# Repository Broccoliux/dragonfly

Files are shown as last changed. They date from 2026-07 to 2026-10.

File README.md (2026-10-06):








 
---
 
# Dragonfly
 
A custom all-in-one flight controller + ESC, built entirely from discrete ICs rather than premade modules, designed for me by me. Flight control and all 4 motor drivers live on a single 4-layer PCB, designed from scratch in KiCad.
 
# Why I Built This
 
I wanted to go past just building a flight controller most DIY FC projects stop at a board that reads a gyro and outputs signals. I wanted the whole thing: FC and ESC combined on one board, IC-level design instead of stacking pre-built modules, a custom 3D-printed frame, and firmware configured to actually fly and hold up to real maneuvers, not just hover.
 
This became a fromscratch systems project schematic, PCB layout, mechanical frame design, and firmware, all built and understood end-to-end rather than assembled from a kit.
 
---
     
## Features
 
- 4-layer PCB designed from scratch in KiCad, all-in-one FC + ESC on a single board
- STM32F405RGTx flight controller MCU running Betaflight, custom unified target
- 4x independent ESC channels, each with its own AT32F421G8U7 MCU running AM32 firmware real per-motor commutation, not a single shared driver
- FD6288Q 3-phase gate drivers + discrete MOSFETs per channel, sized for freestyle current draw, not just hover
- ICM-20602 IMU (SPI), isolated placement and routing to minimize motor-noise coupling into gyro data
- AT7456E OSD for FPV video overlay (battery voltage, timer)
- BMP280 barometer for altitude hold
- TPS5430 buck (5V) + AMS1117-3.3 LDO + dedicated L78L08 8V rail for gate drivers — separate, correctly isolated power domains
- Individual SWD test points per ESC channel for one-time AM32 flashing
- ELRS receiver support (Happymodel Nano RX) over UART
- Custom 3" toothpick-class frame, designed in Fusion 360, 3D printed
- **Estimated build cost:** ~$250–300 (board, motors, frame, battery, receiver, transmitter)
---
 
## What's Inside
 
| Component | Part | Specification |
|---|---|---|
| Flight Controller MCU | STM32F405RGTx | ARM Cortex-M4, 168 MHz |
| IMU | ICM-20602 | 6-axis, SPI |
| ESC MCU (x4) | AT32F421G8U7 | One per motor, runs AM32 |
| Gate Driver (x4) | FD6288Q | 3-phase, one per motor |
| Motor Drive | 6x MOSFET per channel | 24 total, sized for real current draw |
| Buck Regulator | TPS5430 | Battery → 5V |
| LDO | AMS1117-3.3 | 5V → 3.3V |
| Gate Driver Supply | L78L08 | Battery → 8V, dedicated rail |
| OSD | AT7456E | Analog FPV video overlay |
| Barometer | BMP280 | Altitude hold |
| Receiver | Happymodel ELRS Nano RX | UART |
| Transmitter | RadioMaster Zorro (ELRS) | Full-size hall gimbals |
| Motors | 3" class, 1404, ~3800–4500KV | 4S |
| Frame | Custom 3" toothpick | 3D printed, Fusion 360 |
| PCB | 4-layer | KiCad |
 
---
 
## Firmware
 
**Status:** in progress configuration and pin-mapping stage, not reqady to flash
 
Two separate firmware bases run on this board:
 
- **Betaflight** (main STM32F405) custom unified target describing this board's exact pin map (motors, IMU SPI, receiver UART)
- **AM32** (each of the 4 AT32F421 ESC MCUs) open-source ESC firmware, flashed individually per channel via dedicated SWD test points
```bash
firmware/
├── betaflight-unified-target/   # Unified target config for the main FC
├── am32/                        # AM32 firmware source, per-channel builds
└── notes.md                     # Pin mapping reference
```
 
---
 
## How to Use
 
### Hardware
 
1. PCB files are located in `PCB/`
2. Open the `.kicad_pro` file in KiCad 8+
3. Upload Gerbers from `PCB/gerbers/` to JLCPCB (4-layer)
4. Order components using `BOM/BOM.csv`
5. Frame STEP file is available in `CAD/`
### Firmware
 
1. Flash AM32 onto each of the 4 ESC MCUs individually, using the SWD test points per channel
2. Flash Betaflight onto the main STM32 via USB-C, using the custom unified target in `firmware/betaflight-unified-target/`
3. Configure IMU calibration, receiver binding, and OSD via Betaflight Configurator
---
 
## Repository Structure
 
```text
Dragonfly/
├── PCB/                         # KiCad project + Gerbers
├── CAD/                         # Fusion 360 frame design (.step)
├── firmware/                    # Betaflight unified target + AM32
├── BOM/                         # Bill of Materials
├── imgs/                        # Photos and renders
└── README.md
```
 
---
 
## Built By
 
**broccoli 🥦** — Solo hardware builder from Pakistan.
 
*Chasing what I love. GE0*

'geo geo geo

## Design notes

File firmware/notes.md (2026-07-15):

| Function | MCU Pin | Notes |
| --- | --- | --- |
| Motor 1 signal | PA8 | TIM1 CH1, DShot |
| Motor 2 signal | PA9 | TIM1 CH2, DShot (check UART1 conflict) |
| Motor 3 signal | PA10 | TIM1 CH3, DShot (check UART1 conflict) |
| Motor 4 signal | PA11 | TIM1 CH4, DShot |
| IMU SPI | TBD | ICM-20602, SPI, CS/SCK/MISO/MOSI |
| Receiver UART | TBD | ELRS, avoid USART1 if motors use PA9/PA10 |

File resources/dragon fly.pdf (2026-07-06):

## BROCCOLI BOARD LAB

# Phased Build Guide

## Custom FC+ESC Drone — Component by Component, Item by Item

Revised: freestyle-capable ESC · custom 3D-printed frame · transmitter included

Prepared for broccoli ■ — July 2026

Phased Build Guide — Custom FC+ESC Drone | Page 2

# Index

Index | 2
How This Guide Works | 3
Designing the Custom 3D-Printed Frame | 9
Appendix — Updated Bill of Materials | 10

# How This Guide Works

Each component is one phase. Each phase has numbered items — the exact supporting parts (capacitors, resistors, ferrite beads, crystals) that go with that component. Finish every item in a phase, double-check it against the datasheet reference, then move to the next phase. Don't jump ahead — if something breaks later, you want to know it's isolated to the most recent phase, not spread across five half-finished ones.
Build order: MCU → IMU → ESC channel (repeated 4x, one per motor) → Power → Peripherals. This order is deliberate — the MCU's pin assignments have to be locked before anything else can be wired to them.

Phase 1: Microcontroller — STM32F405RGT6

## PHASE 1: Microcontroller — STM32F405RGT6

LQFP-64 · the flight computer · lock every pin assignment here before moving on

Item 1: Power pins
- 100nF ceramic decoupling capacitor on every single VDD pin — do not skip any.
- 1x 4.7–10µF bulk capacitor on the main VDD rail.

Item 2: Analog reference
- 100nF + 1µF on VDDA/VREF+, isolated from digital VDD with a small ferrite bead.

Item 3: Backup rail
- 10nF + 1µF on VBAT, even without a backup RTC battery.

Item 4: Clock
- 1x 8MHz HSE crystal (3225 SMD).
- 2x load capacitors matched to the crystal's specified load capacitance (commonly 10–20pF each).

Item 5: Programming and reset
- 4-pin SWD header: SWDIO, SWCLK, GND, 3V3.
- BOOT0 pushbutton or jumper to enter DFU flashing mode.
- NRST pushbutton with 100nF capacitor to GND for debounce.
Before moving on: write down which physical pins you assigned to SPI (for the IMU), which timer channels you assigned to each motor (for the ESCs), and which UART you assigned to the receiver. Every later phase depends on this list.

Datasheet: STM32F405RGT6, STMicroelectronics — https://www.lcsc.com/datasheet/C15742.pdf

Phase 2: IMU — ICM-20602

## PHASE 2: IMU — ICM-20602

3x3mm QFN · gyro + accelerometer · most noise-sensitive part on the board

Item 1: Power decoupling
- 100nF ceramic on VDD, placed as close to the pin as physically possible.
- 100nF ceramic on VDDIO if IO voltage differs from core VDD.

Item 2: SPI wiring
- SCLK, MOSI, MISO, CS to the SPI pins you assigned in Phase 1.
- Keep these traces short; route away from any motor/ESC power traces.

Datasheet: ICM-20602, TDK InvenSense — https://invensense.tdk.com/wp-content/uploads/2016/10/DS-000176-ICM-20602-v1.0.pdf

Phase 3: ESC Channel Template (build once, repeat x4)

## PHASE 3: ESC Channel Template

AT32F421 + FD6288Q + 6x MOSFET · build this block once, then repeat it identically 3 more times, one per motor

This replaces a single integrated driver chip with the real architecture used in freestyle-capable ESCs: a dedicated small MCU per motor, running AM32 firmware, driving a 3-phase gate driver, driving 6 discrete MOSFETs. A fully open-source reference design exists for this exact combination — incutec-hw/OpenESC_20X20 on GitHub — KiCad source, 20x20mm, 30A/channel, AT32F421 + AM32, Betaflight-compatible. Use it to cross-check every value below.

Item 1: Per-channel MCU — AT32F421G8U7
- 100nF decoupling capacitor on VDD.
- 100nF + 1µF on VDDA.
- SWD header (SWDIO, SWCLK, GND, 3V3) for flashing the AM32 bootloader — needed once per channel during assembly.
- Single-wire signal connection back to the main STM32 (this carries DShot).

Item 2: Gate driver — FD6288Q
- 3x bootstrap capacitors (one per half-bridge), value per the OpenESC_20X20 reference — typically in the 100nF–1µF range for this driver.
- 100nF decoupling on VCC.
- Gate resistors between each driver output and its MOSFET gate, sized to control switching speed and ringing — verify exact value against the reference design rather than guessing.

Item 3: Power stage — 6x N-channel MOSFETs (3 half-bridges)
- Choose MOSFETs with continuous drain current at least double your expected per-motor current draw — pulsed switching is harder on a MOSFET than steady DC.
- Confirm exact part number and footprint from the OpenESC_20X20 BOM before ordering — this is the one value worth copying exactly rather than approximating.
- 1x bulk low-ESR, high-ripple-current capacitor per channel on the motor supply rail (rule of thumb from the AM32 hardware design guide: undersizing this causes ESCs to fail under rapid current swings).

Item 4: Motor output
- 3 phase pads per channel, routed to a connector or direct solder pad for the motor's 3 wires.
Repeat this entire phase 3 more times — once per motor — before moving to Phase 4.

Reference hardware (KiCad, open source): https://github.com/incutec-hw/OpenESC_20X20

AT32F421 datasheet: https://www.lcsc.com/datasheet/lcsc_datasheet_2206061416_ARTERY-AT32F421G8U7_C2765098.pdf

FD6288Q datasheet: https://lcsc.com/datasheet/lcsc_datasheet_2411011654_Fortior-Tech-FD6288Q_C328453.pdf

AM32 hardware design guide: https://wiki.am32.ca/development/Hardware-Design.html

Phase 4: Power — Buck + LDO

## PHASE 4: Power — Buck (5V) + LDO (3.3V)

Battery to 5V to 3.3V · build last, now that real current draw across all 4 ESC channels is known

Item 1: Input protection
- 1x Schottky diode (≥40V, ≥3A) in series with battery positive for reverse-polarity protection.
- 1x bulk capacitor (100–220µF, ≥25V) across the battery input.

Item 2: Buck regulator — TPS5430
- 10µF input ceramic capacitor near VIN.
- Inductor, 10–33µH, rated for at least 3A saturation — use TI's WEBENCH tool for your exact values.
- Schottky catch diode (≥40V, 3A) — required, this is a non-synchronous buck.
- ~220µF output capacitance (ceramic + electrolytic).
- Feedback resistor divider set for 5V output.

Item 3: LDO — AMS1117-3.3
- 10µF input capacitor.
- 10µF tantalum output capacitor (needs some ESR for stability — not pure ceramic).

Datasheet TPS5430: https://www.ti.com/lit/ds/symlink/tps5430.pdf

Datasheet AMS1117: http://www.advanced-monolithic.com/pdf/ds1117.pdf

Phase 5: Peripherals (optional)

## PHASE 5: Peripherals (Optional)

OSD, barometer, current sense, USB-C, receiver header — build any/all last

Item 1: USB-C flashing port
- 2x 5.1kΩ pull-down resistors on CC1/CC2.
- D+/D– direct to the STM32's USB OTG FS pins.

Item 2: ELRS receiver header
- 3–4 pin header: power, GND, TX, RX to a spare UART.
- No extra passives needed — the receiver module has its own regulation.

Item 3: OSD — AT7456E (skip if not running FPV video)
- 100nF on digital VDD; 100nF + 10µF on analog video supply.
- Separate SPI CS line from the IMU.

Item 4: Barometer — BMP280 (optional)
- 100nF on VDDIO and VDD; I2C with 4.7–10k pull-ups.

Item 5: Current sense — INA240 (optional)
- Shunt resistor in the main battery path; 100nF on VS; output to an MCU ADC pin.

# Designing the Custom 3D-Printed Frame

This is a mechanical design problem, not an electronics one — the two failure modes to design around are propeller strikes (wrong clearance) and vibration reaching the IMU (arms too flexible).

Decision | Recommendation | Why
Material | PETG or Nylon | PLA is too brittle — cracks on hard landings instead of flexing
Wheelbase | 120–150mm motor-to-motor (diagonal) | Must clear 3" (76mm) prop diameter with margin at full lean angle
Arm print orientation | Flat, layer lines running lengthwise | Vertical layers delaminate under vibration — the #1 cause of 3D-printed frame failure
Arm construction | Bolt-on, replaceable per arm | A crash breaks one cheap arm instead of the whole frame
PCB mounting | M3 standoffs on the 20x20mm pattern + soft rubber grommets | Grommets isolate motor vibration before it reaches the gyro
Motor bolt pattern | Confirm exact pattern (commonly M2, 9x12mm) from your specific motor before finalizing arm-end geometry | Wrong hole spacing means the motor simply doesn't bolt on

Design process:
- Model the center plate first — it carries the PCB mounting holes (20x20mm) and defines where arms attach.
- Model one arm, with the motor mounting pattern at the far end and a bolt-on interface to the center plate.
- Pattern the arm 4 times around the center plate at your chosen wheelbase.
- Check prop clearance in CAD with the actual prop diameter modeled — not just eyeballed.
- Print one arm first as a test piece before committing to a full set — verify motor bolt pattern and clearance physically before printing the whole frame.
- Use Fusion 360 (same tool used for the Broccoli Board case) — same workflow, new geometry problem.

# Appendix — Updated Bill of Materials

Ordering reference only — build using the phases above.

Qty | Part | Approx. Price | Notes
1 | STM32F405RGT6 | $4.50 | Main flight MCU
1 | ICM-20602 | $2.20 | IMU
4 | AT32F421G8U7 | $4.00 (4x) | One ESC MCU per motor, runs AM32
4 | FD6288Q | $1.60 (4x) | One gate driver per motor
24 | N-channel MOSFETs | $14.00 (24x) | 6 per motor channel — confirm exact part vs. OpenESC_20X20 BOM
1 | TPS5430 | $1.50 | 5V buck
1 | AMS1117-3.3 | $0.10 | 3.3V LDO
4 | Brushless motors (3" class, e.g. 1404–1606, ~3800–4500KV) | $24.00 (4x) | Sized for real freestyle current draw, not just hover
1 set | 3" props (2x CW, 2x CCW) | $6.00 | Keep spares — you will break some
1 | 4S LiPo battery + charger | $25.00 | Matches motor KV choice
1 | Happymodel ELRS Nano RX | $12.00 | Bought module, UART to main MCU
1 | RadioMaster Zorro (ELRS) | $70–100 | Handheld transmitter — not optional, was missing from original budget
1 set (5pcs) | PCB fabrication (4-layer) | $15–20 | JLCPCB or similar
— | Frame filament (PETG/Nylon) | $8–12 | Custom printed frame
— | Passives (caps/resistors/diodes) | ~$8.00 | Across all phases

Estimated grand total: ~$250–300, all-in — board, motors, frame material, battery, receiver, and transmitter. This is the honest cost of a board built for real maneuvers, not just hover.

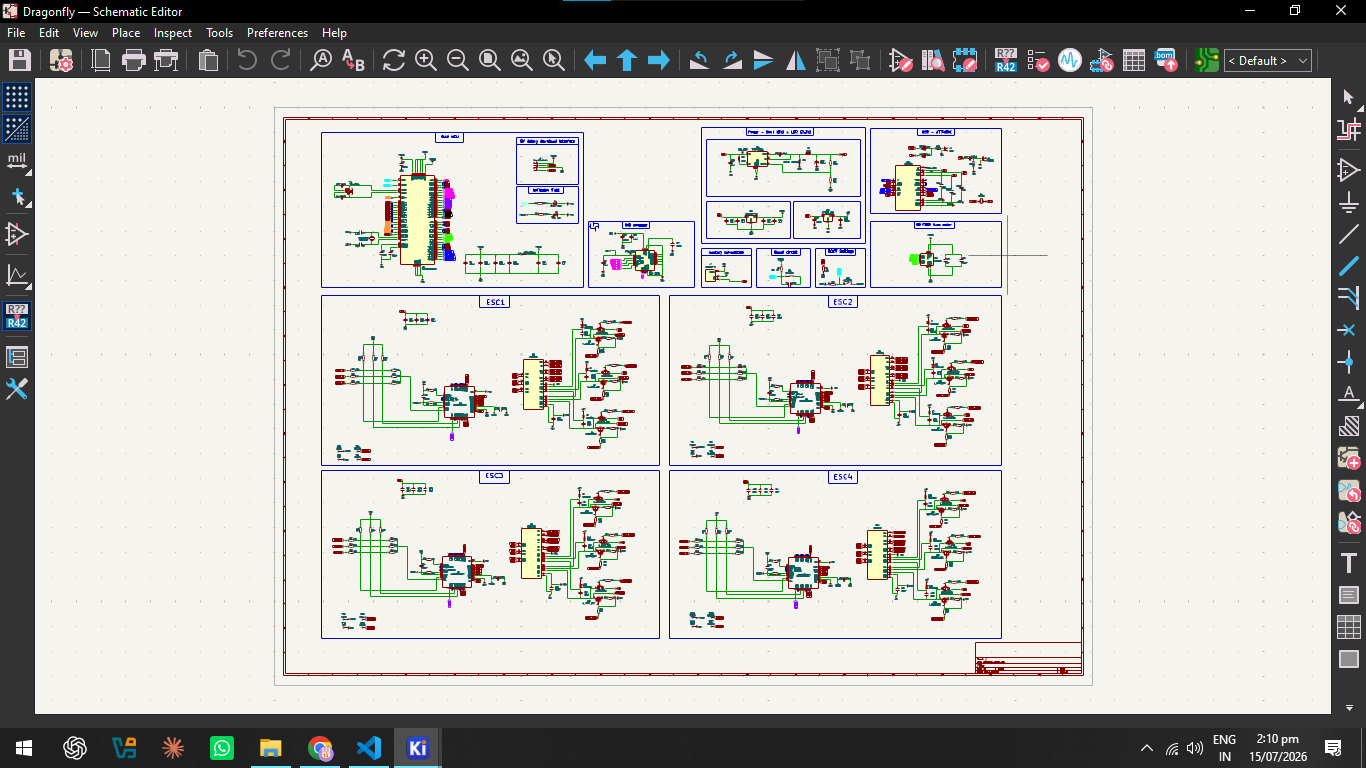
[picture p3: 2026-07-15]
imgs/schematics.png

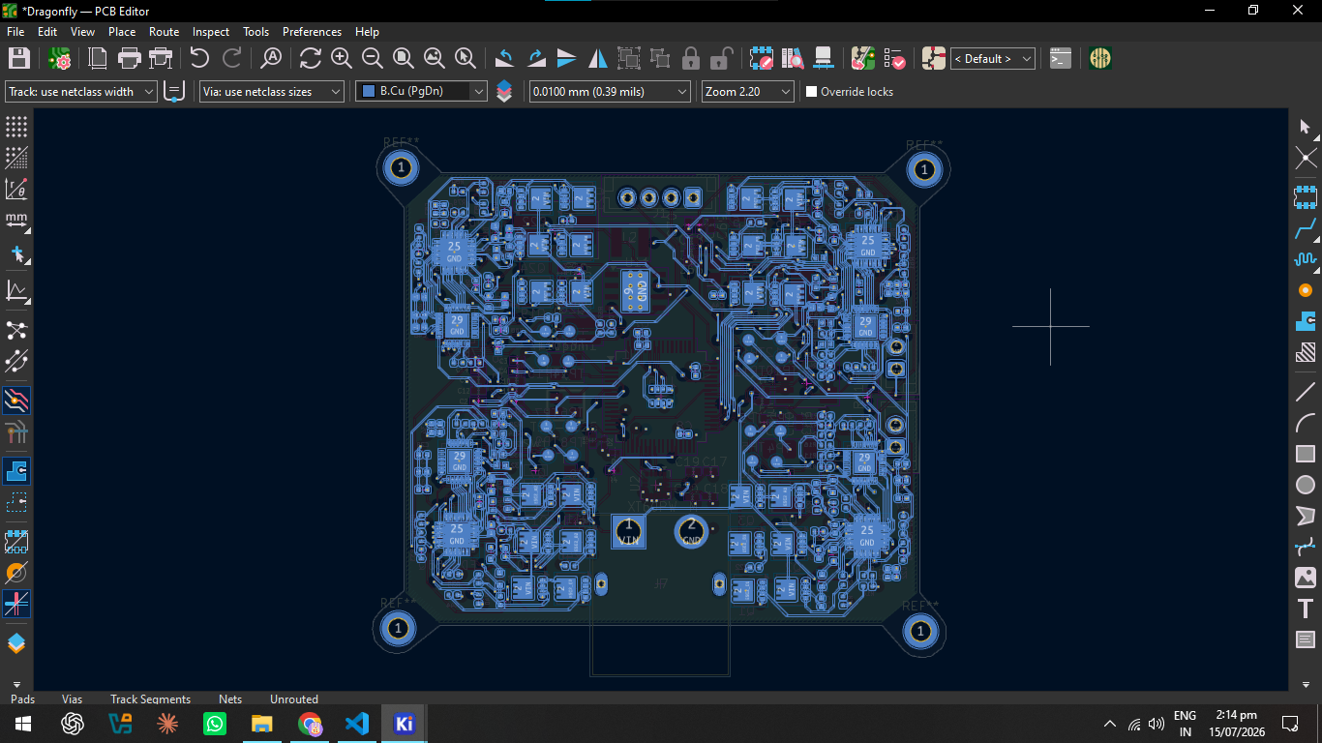
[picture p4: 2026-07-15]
imgs/PCB f.cu.png

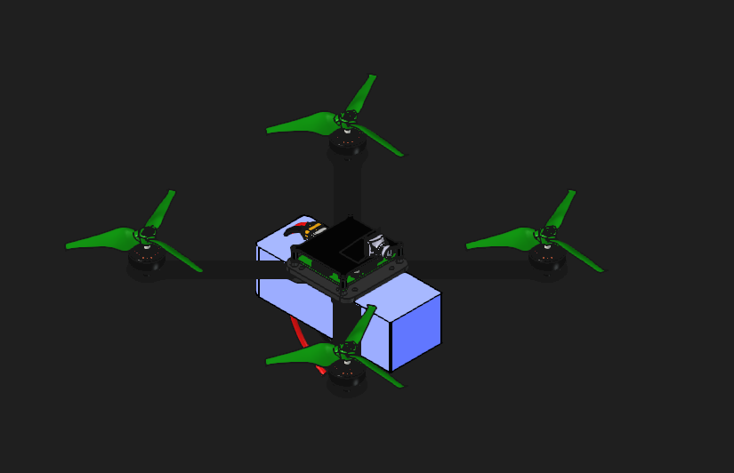
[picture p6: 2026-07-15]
imgs/wow.png

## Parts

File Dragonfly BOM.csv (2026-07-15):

Reference | Qty | Value | DNP | Exclude from BOM | Exclude from Board | Footprint | Datasheet
+10ppm1 | 1 | 32.768 kHz |  |  |  | Crystal:Crystal_SMD_3225-4Pin_3.2x2.5mm
C1,C2 | 2 | 10pf |  |  |  | Capacitor_SMD:C_0402_1005Metric
C3,C4 | 2 | 12pf |  |  |  | Capacitor_SMD:C_0402_1005Metric
C5,C6,C9,C10,C11,C12,C17,C19,C21,C22,C23,C26,C32,C34,C35,C36,C41,C43,C44,C45,C50,C52,C53,C54,C64,C65,C66,C67,C68,C69 | 30 | 100nf |  |  |  | Capacitor_SMD:C_0402_1005Metric
C7,C8,C18 | 3 | 2.2uf |  |  |  | Capacitor_SMD:C_0402_1005Metric
C13 | 1 | 10nf |  |  |  | Capacitor_SMD:C_0402_1005Metric
C14,C61,C63,C72 | 4 | 1uf |  |  |  | Capacitor_SMD:C_0402_1005Metric
C20,C24,C25,C27,C28,C29,C30,C31,C33,C37,C38,C39,C40,C42,C46,C47,C48,C49,C51,C55,C56,C57,C60,C62 | 24 | 10uf |  |  |  | Capacitor_SMD:C_0402_1005Metric
C58 | 1 | 0.01uf |  |  |  | Capacitor_SMD:C_0402_1005Metric
C59 | 1 | 220uf |  |  |  | Capacitor_SMD:CP_Elec_6.3x5.8
C70,C71 | 2 | 47uf |  |  |  | Capacitor_SMD:C_0402_1005Metric
C73 | 1 | 0.1uf |  |  |  | Capacitor_SMD:C_0402_1005Metric
D1 | 1 | LED BLUE |  |  |  | LED_SMD:LED_0201_0603Metric
D2 | 1 | LED RED |  |  |  | LED_SMD:LED_0201_0603Metric
D3,D4,D5,D6,D7,D8,D9,D10,D11,D12,D13,D14 | 12 | 1N914WT |  |  |  | Diode_SMD:D_SOD-523 | http://www.mouser.com/ds/2/149/1N4148WT-461550.pdf
D15 | 1 | 40V, 3A Schottky |  |  |  | Diode_SMD:D_SMC | http://www.jameco.com/Jameco/Products/ProdDS/1538777.pdf
J1 | 1 | Conn_01x04_Pin |  |  |  | Connector_JST:JST_EH_B4B-EH-A_1x04_P2.50mm_Vertical
J7 | 1 | XT60PW-M |  |  |  | XT60PW-M:AMASS_XT60PW-M
J8 | 1 | CAM VIN |  |  |  | Connector_JST:JST_EH_B2B-EH-A_1x02_P2.50mm_Vertical
J9 | 1 | VOUT |  |  |  | Connector_JST:JST_EH_B2B-EH-A_1x02_P2.50mm_Vertical
L1 | 1 | 1KΩ 100Mhz |  |  |  | Inductor_SMD:L_0402_1005Metric
L2 | 1 | 15uh |  |  |  | Inductor_SMD_Wurth:L_Wurth_WE-LQSH-4020
Q1,Q2,Q3,Q4,Q5,Q6,Q7,Q8,Q9,Q10,Q11,Q12,Q13,Q14,Q15,Q16,Q17,Q18,Q19,Q20,Q21,Q22,Q23,Q24 | 24 | Q_NMOS_GDS |  |  |  | Package_SON:Diodes_PowerDI3333-8
R1 | 1 | 10k NC |  |  |  | Resistor_SMD:R_0402_1005Metric
R2,R3,R7,R8,R9,R10,R11,R15,R16,R17,R27,R28,R29,R33,R34,R35,R36,R37,R47,R48,R49,R53,R54,R55,R56,R57,R67,R68,R69,R73,R74,R75,R76,R77,R88 | 35 | 10k |  |  |  | Resistor_SMD:R_0402_1005Metric
R4,R5 | 2 | 5.1kΩ |  |  |  | Resistor_SMD:R_0402_1005Metric
R12,R13,R14,R30,R31,R32,R50,R51,R52,R70,R71,R72 | 12 | 1k |  |  |  | Resistor_SMD:R_0402_1005Metric
R18,R22,R26,R42,R44,R46,R62,R64,R66,R82,R84,R86 | 12 | 0R |  |  |  | Resistor_SMD:R_0402_1005Metric
R19,R20,R21,R23,R24,R25,R38,R39,R40,R41,R43,R45,R58,R59,R60,R61,R63,R65,R78,R79,R80,R81,R83,R85 | 24 | 20R |  |  |  | Resistor_SMD:R_0402_1005Metric
R87 | 1 | 30.9k |  |  |  | Resistor_SMD:R_0815_2038Metric
R89 | 1 | 100k |  |  |  | Resistor_SMD:R_0402_1005Metric
R90,R91 | 2 | 75R |  |  |  | Resistor_SMD:R_0402_1005Metric
SW1,SW2 | 2 | SW_SPST |  |  |  | Button_Switch_SMD:SW_Tactile_SPST_NO_Straight_CK_PTS636Sx25SMTRLFS
TP2,TP6,TP10,TP14 | 4 | VDD33 |  |  |  | TestPoint:TestPoint_Pad_D1.0mm
TP3,TP7,TP11,TP15 | 4 | GND |  |  |  | TestPoint:TestPoint_Pad_D1.0mm
TP4 | 1 | SWCLK1 |  |  |  | TestPoint:TestPoint_Pad_D1.0mm
TP5 | 1 | SWDIO1 |  |  |  | TestPoint:TestPoint_Pad_D1.0mm
TP8 | 1 | SWCLK2 |  |  |  | TestPoint:TestPoint_Pad_D1.0mm
TP9 | 1 | SWDIO2 |  |  |  | TestPoint:TestPoint_Pad_D1.0mm
TP12 | 1 | SWCLK3 |  |  |  | TestPoint:TestPoint_Pad_D1.0mm
TP13 | 1 | SWDIO3 |  |  |  | TestPoint:TestPoint_Pad_D1.0mm
TP16 | 1 | SWCLK4 |  |  |  | TestPoint:TestPoint_Pad_D1.0mm
TP17 | 1 | SWDIO4 |  |  |  | TestPoint:TestPoint_Pad_D1.0mm
U1 | 1 | STM32F405RGTx |  |  |  | Package_QFP:LQFP-64_10x10mm_P0.5mm | https://www.st.com/resource/en/datasheet/stm32f405rg.pdf
U2 | 1 | ICM-20602 |  |  |  | Package_LGA:LGA-16_3x3mm_P0.5mm_LayoutBorder3x5y | http://www.invensense.com/wp-content/uploads/2016/10/DS-000176-ICM-20602-v1.0.pdf
U3,U5,U7,U9 | 4 | AT32F421G8U7 |  |  |  | Library:AT32F421G8U7
U4,U6,U8,U10 | 4 | FD6288Q |  |  |  | FD6288Q:QFN50P400X400X90-25N
U11 | 1 | TPS5430DDA |  |  |  | Package_SO:TI_SO-PowerPAD-8_ThermalVias | http://www.ti.com/lit/ds/symlink/tps5430.pdf
U12 | 1 | AMS1117-3.3 |  |  |  | Package_TO_SOT_SMD:SOT-223-3_TabPin2 | http://www.advanced-monolithic.com/pdf/ds1117.pdf
U13 | 1 | L78L08_SO8 |  |  |  | Package_SO:SOIC-8_3.9x4.9mm_P1.27mm | http://www.st.com/content/ccc/resource/technical/document/datasheet/15/55/e5/aa/23/5b/43/fd/CD00000446.pdf/files/CD00000446.pdf/jcr:content/translations/en.CD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
U14 | 1 | AT7456E |  |  |  | AT7456E:SOP65P640X120-29N
U15 | 1 | BMP280 |  |  |  | Package_LGA:Bosch_LGA-8_2x2.5mm_P0.65mm_ClockwisePinNumbering | https://ae-bst.resource.bosch.com/media/_tech/media/datasheets/BST-BMP280-DS001.pdf
X1 | 1 | TSX-3225 |  |  |  | TSX-3225:TSX-3225
Y1 | 1 | 27MHZ |  |  |  | Crystal:Crystal_SMD_3225-4Pin_3.2x2.5mm

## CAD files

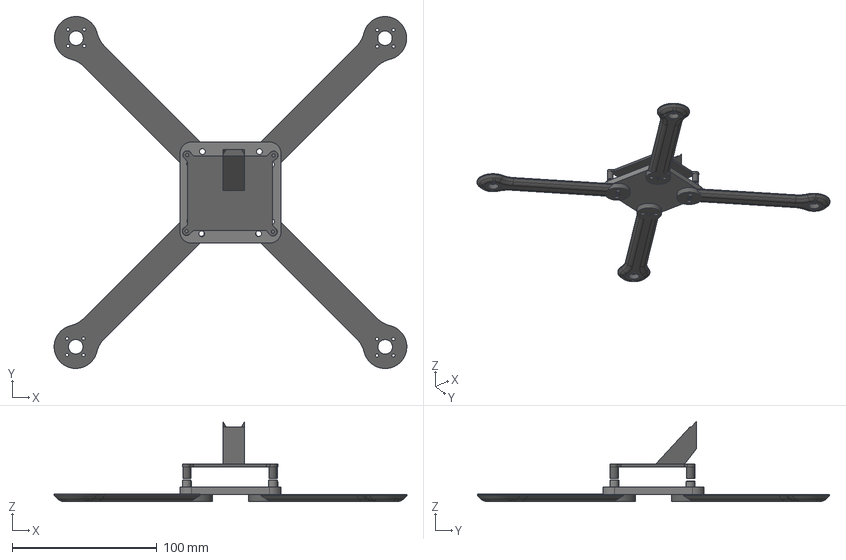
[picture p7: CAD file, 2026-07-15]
CAD/dragonfly CAD full.step
244.0 x 243.5 x 55.3 mm
arm 1
arm 3
arm 4
arm 2
battery frame
cam wall

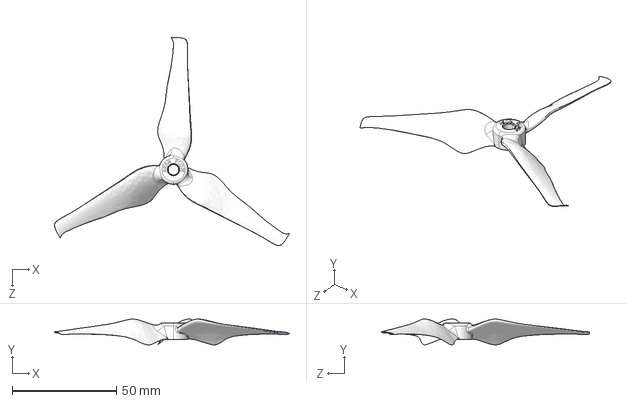
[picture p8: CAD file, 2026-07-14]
CAD/external 3d models/Emax Avan Flow/EMAX AVAN FLOW CW.STEP
112.7 x 12.4 x 99.9 mm

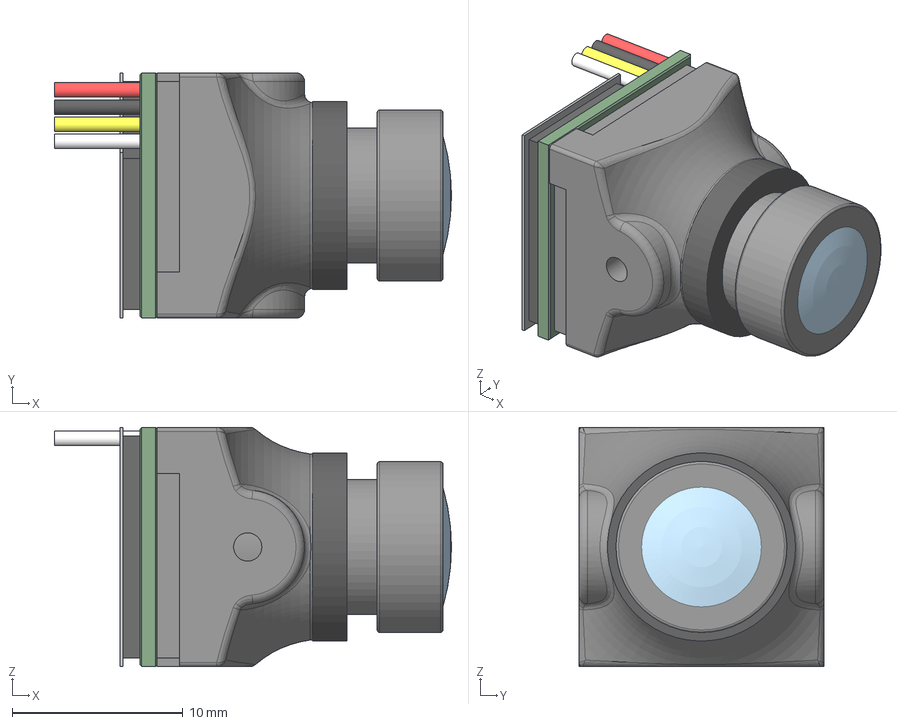
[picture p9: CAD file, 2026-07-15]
CAD/external 3d models/FOXEER TOOTHLESS 2 NANO/FOXEER TOOTHLESS 2 NANO CAMERA.stp
23.2 x 14.4 x 14.0 mm

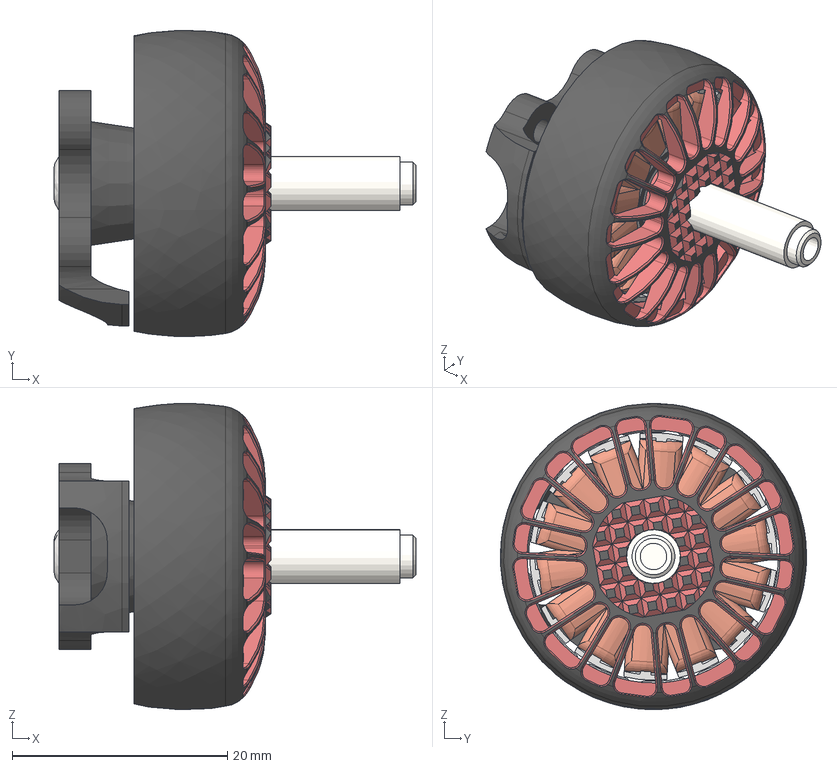
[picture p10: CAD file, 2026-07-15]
CAD/external 3d models/iflight-xing-2207/iFlight.Xing.2207.stp
33.7 x 28.5 x 28.5 mm
Rotor.iFlight.2207
Eixo iFlight 2207
Estator.iFlight.2207
JIS B 1521 - 684 4x9x2.5 x 2
Mancal.Estator.iFlight.2207
ANSI B18.3.4M - M3 x 0.5 x 3, BHSBHCSM

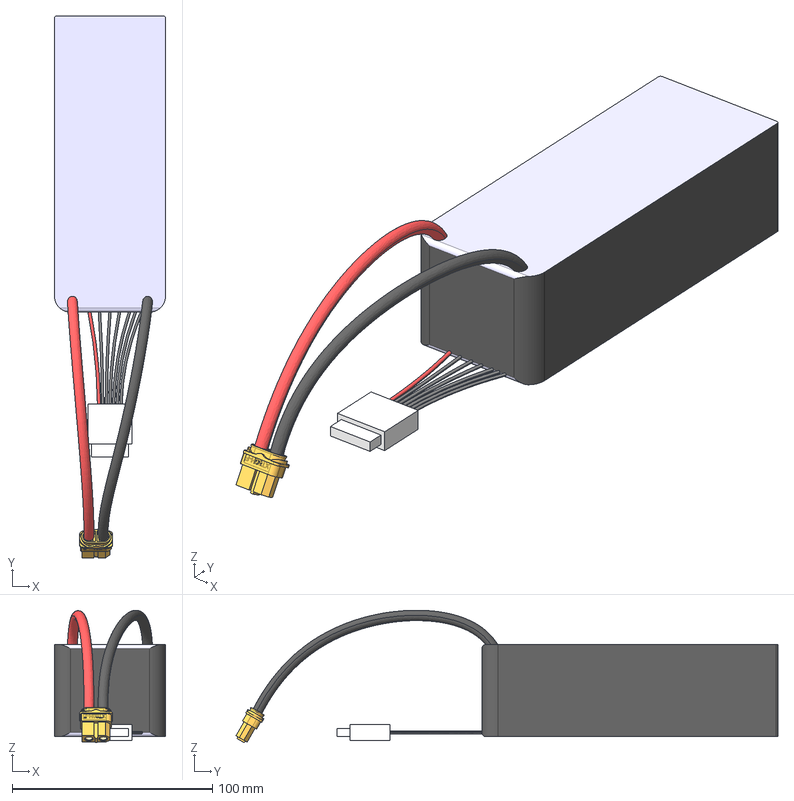
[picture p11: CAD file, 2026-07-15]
CAD/external 3d models/TATTU battery/Tattu_6S_6000mAh_35C.stp
55.5 x 270.9 x 66.2 mm
Battery 6000 6S
Housing
Contact x 2

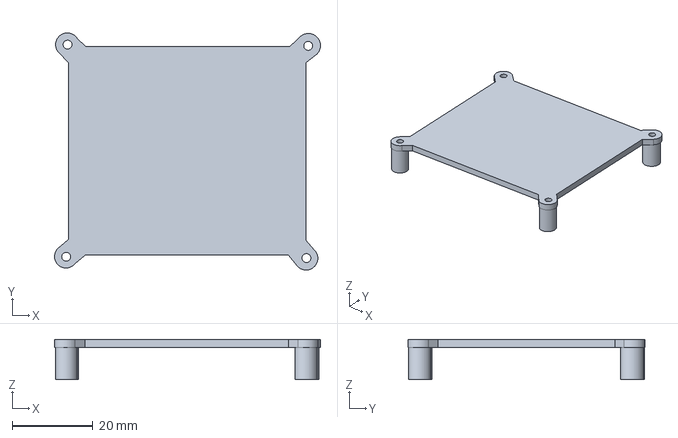
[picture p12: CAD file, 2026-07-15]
CAD/PCB cover.step
66.0 x 58.9 x 10.0 mm

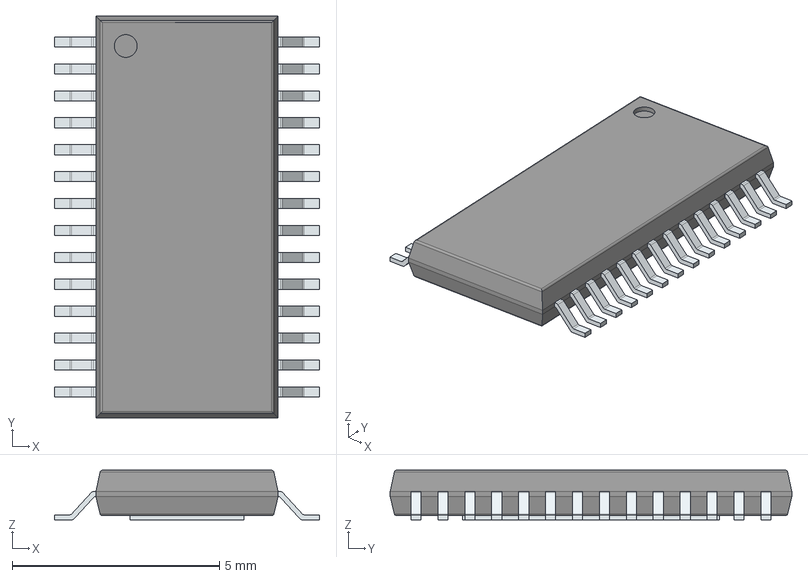
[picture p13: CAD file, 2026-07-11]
resources/symbols/AT7456E/3D/AT7456E.stp
6.40 x 9.70 x 1.20 mm
PinsArrayLR
ThermalPad

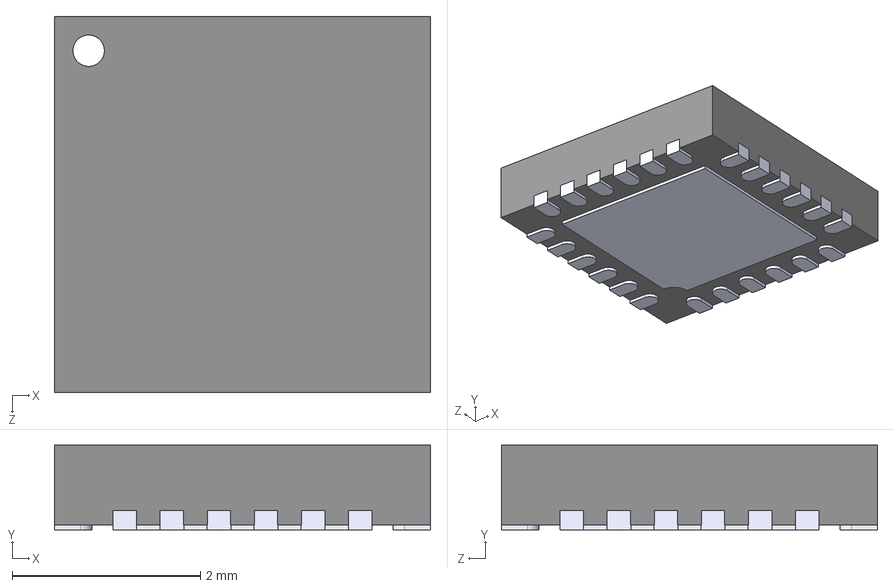
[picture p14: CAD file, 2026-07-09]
resources/symbols/FD6288Q/FD6288Q.step
4.00 x 0.9 x 4.00 mm

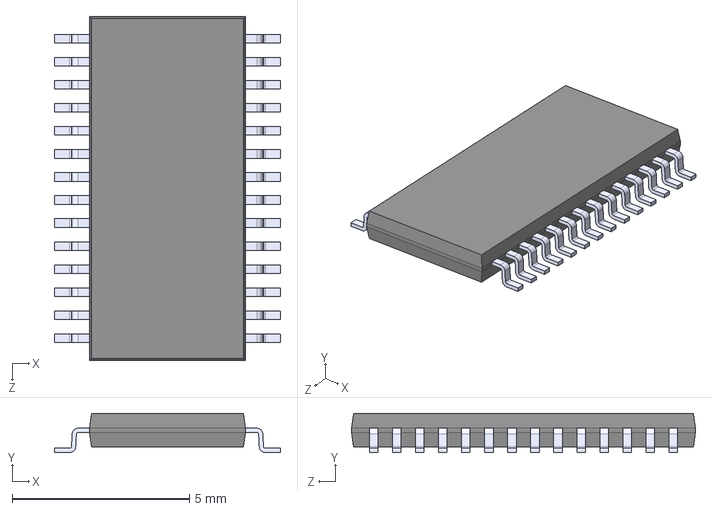
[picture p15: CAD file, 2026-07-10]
resources/symbols/MAX7456_AT7456/MAX7456EUI.step
6.38 x 1.10 x 9.70 mm

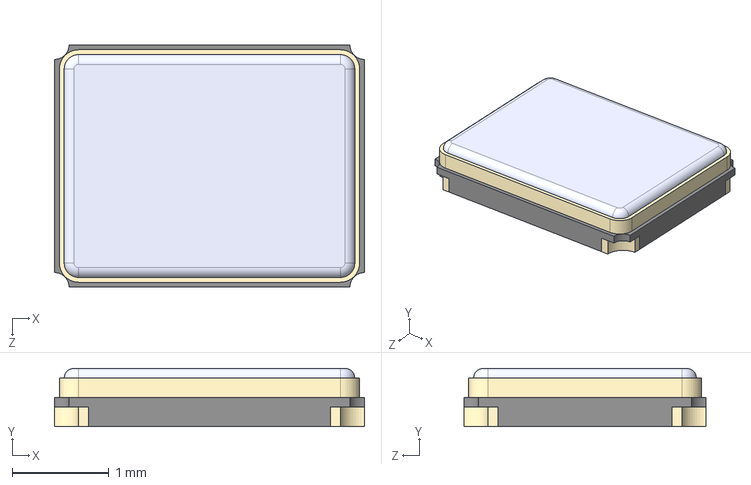
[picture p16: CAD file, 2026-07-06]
resources/symbols/OpenESC_20X20-main/TSX-3225/TSX-3225.step
3.20 x 0.6 x 2.50 mm

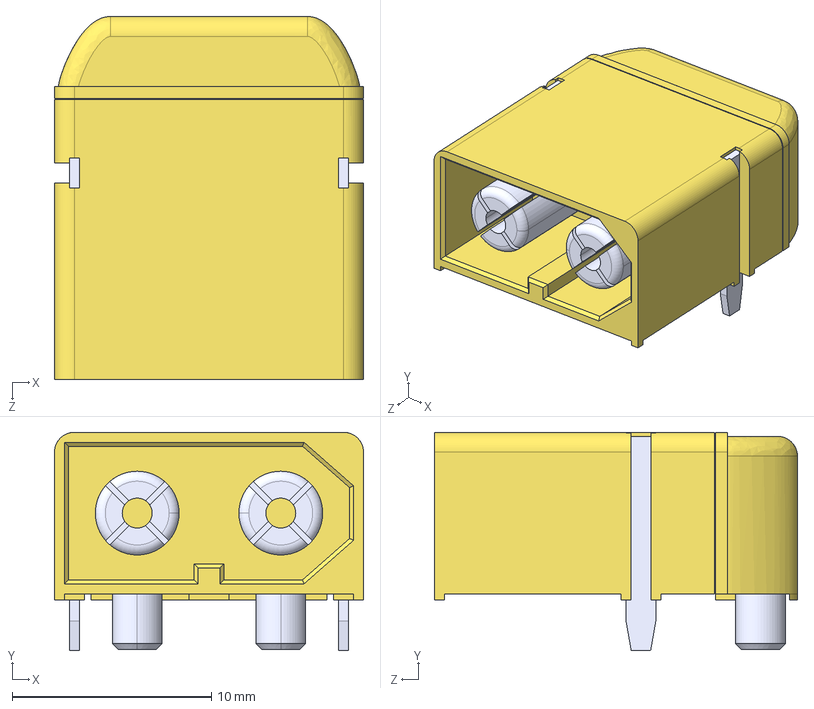
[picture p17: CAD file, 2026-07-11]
resources/symbols/XT60PW-M/XT60PW-M.step
15.5 x 10.9 x 18.2 mm

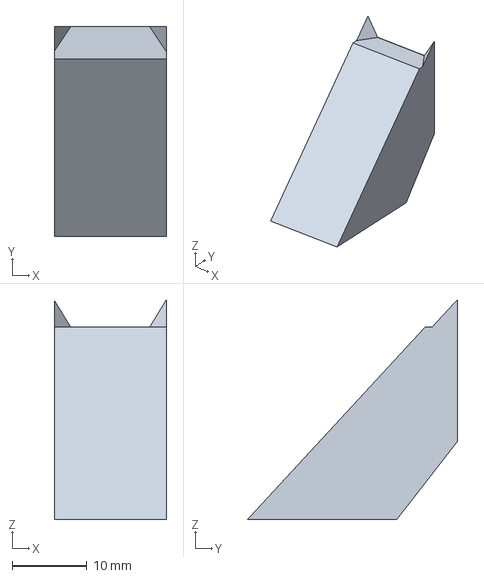
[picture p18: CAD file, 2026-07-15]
CAD/Cam wall.step
15.0 x 28.1 x 29.5 mm

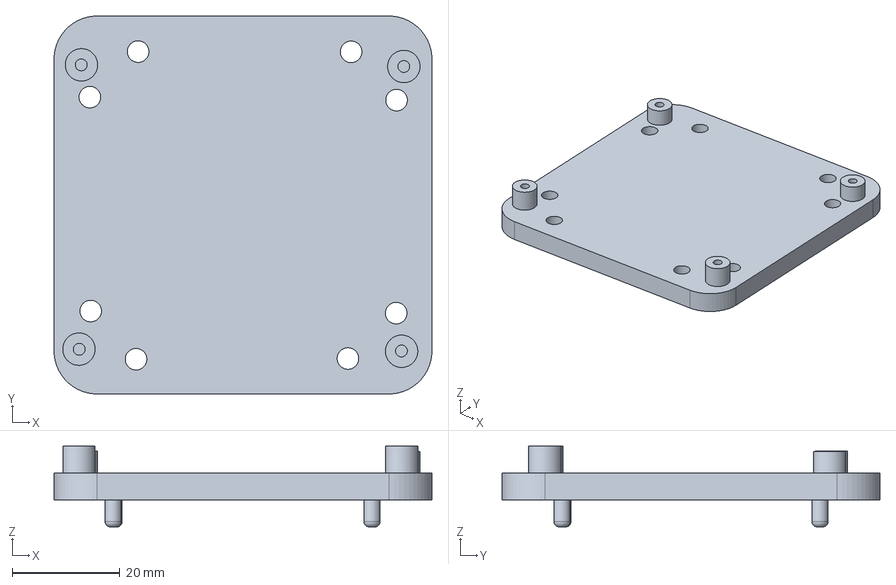
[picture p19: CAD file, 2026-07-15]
CAD/base.step
70.0 x 70.0 x 15.0 mm

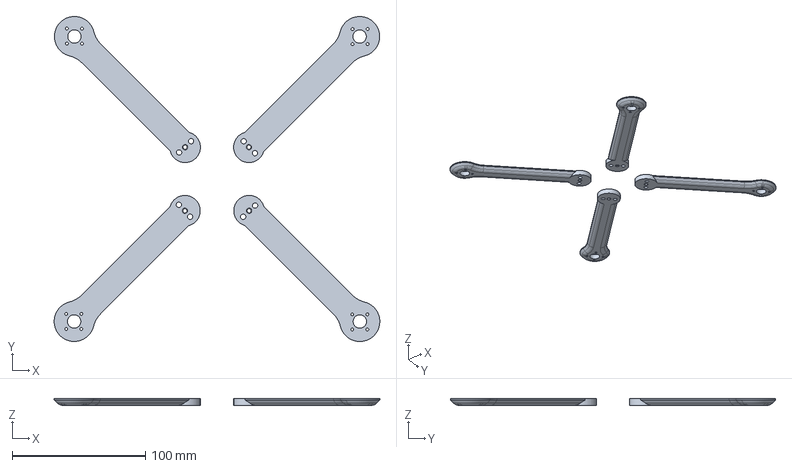
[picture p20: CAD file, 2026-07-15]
CAD/arms.step
244.0 x 243.5 x 5.10 mm
arm 1
arm 3
arm 4
arm 2

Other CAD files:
CAD/external 3d models/Emax Avan Flow/EMAX AVAN FLOW CCW.STEP
CAD/external 3d models/Emax Avan Flow/EMAX AVAN FLOW CW.sldprt
CAD/external 3d models/FOXEER TOOTHLESS 2 NANO/FOXEER TOOTHLESS 2 NANO CAMERA.stl
resources/symbols/AT7456E/Allegro/sop65p640x120-29n.psm
resources/symbols/AT7456E/DEHDL/at7456e/chips/chips.prt

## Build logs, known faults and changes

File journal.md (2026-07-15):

## ALL daily journals will can be seen here.

### 06/07/2036

## TOPIC: researching the componrnts. DATA Sheet reading

so today i am going to research about the componnets and the teach stack i am gonna use. i have the a guide file using claude after discussing are we gonna build, and what are the right and the best value for monay components we should use.
first i will read the full the guide then i will search the about componets and there data sheets.

found the data sheets for the main MCU  STM32F405RGT6, 


neevr used something like this before, it haev 51 gpios that absolutly crazy, lets see how it goes.


lol my system go freez as i open the refrance schemtic website. fahhh

one more thing (for the reviewer) that i always read the almost full data sheets to learn everything about it, this is what i haev done in fallout, just wanted to tell, :)

i was reading the data sheet and get to know that we are usinf the lowest power IC, not the the lowest power but there are what are why better then this. like  STM32F407Ix which haev 140 GPIOs but when i asked my mentor (claude) why not we use the STM32F407Ix he said, 
```
1. Package size — the big one for a drone. STM32F407Ix comes in LQFP176 or UFBGA176 — a huge package (24×24mm or BGA). Your F405RGT6 is LQFP64 (10×10mm). On a weight- and space-constrained 3" toothpick board, that's a massive difference — the 407I package alone could be bigger than your entire current board footprint.
2. BGA is a real assembly problem. If you go with a BGA variant of the 407, you can't hand-solder or even hot-air it reliably — BGA packages have solder balls hidden underneath, invisible during reflow, and typically need X-ray inspection to verify. That's a fab-house assembly service requirement, not a DIY bench build.
3. The extra features are dead weight for a flight controller. F407 adds Ethernet MAC and a camera interface (DCMI) over the F405 — neither is used by Betaflight or any FC firmware. You'd be paying for and routing pins for silicon you'll never touch.
4. Community/reference design mismatch. F405 (and F411, F722, F745) are the actual chips the entire Betaflight hardware ecosystem is built around — that's why OpenESC-style projects and every AIO board reference schematic target these specifically. F407 basically doesn't show up in FC reference designs, so you'd be flying blind without community schematics to check against — the exact thing you told me you wanted to avoid from the start.
5. Cost. F407I parts run more than F405RG for capability you don't need.
Net: F405RGT6 gives you the same core (Cortex-M4, 168MHz, same peripherals that actually matter — SPI, timers, USB) in a smaller, hand-solderable package, with real community backing. F407Ix is the wrong tool here, not a worse version of the right one — it's built for networked embedded systems, not flight controllers.
```
fair point right? this is the reason i prefer reading full data sheet we get to know so many use full things.

i should must keep the temps in my cuz they are really imp. why, cuz i bured few components by not checking the solder tempreture, the SOD light melt instently, lol


found the really great info, that i also shoudl keep in mind:


idk if this thing i imp to read, cuz it looks difficult
hell hell hell



maybe i shoudl not miss that imp info, and ask claude to help me understand it.
claude told i dont have to read this completely, just need to find few things and stick with them, this what claude said.
```
Not all of it — and honestly, most of that diagram doesn't apply to you at all.
This block diagram covers the whole family (F405 + F407 together), so it includes stuff like the Ethernet MAC, camera interface, and USB OTG HS — those are F407-only features baked into your F405's chip too but physically don't exist as usable pins in your smaller LQFP64 package. Ignore all of that.
What you actually need to find and understand on this diagram (everything else is noise for this project):

GPIO Port A-I — where your pins physically live
TIM1-TIM14 (the timer blocks) — this is what generates PWM/DShot to your 4 ESCs
SPI1/2/3 — this is your IMU connection
USART1-6 / UART4-5 — this is your ELRS receiver connection
USB OTG FS (not the HS one) — this is your flashing port
ADC1-3 — only relevant if you add the optional current sense later
Power management section (VDD, VDDA, POR/PDR, reset & clock control) — this is what your Phase 1 decoupling caps actually connect to

Don't try to "read" this like a book front to back. Use it like a map — when you're wiring something specific (say, "which SPI do I use for the IMU"), come back to this diagram and trace just that one block. Trying to absorb the whole thing at once is exactly why it looks like hell — it's not written to be read linearly, it's written to be referenced.
You don't need to memorize this. You need to know it exists so when Phase 1 says "assign SPI pins," you know where to look.
```

all i have to focus is on these:
GPIO Port A-I — where your pins physically live
TIM1-TIM14 (the timer blocks) — this is what generates PWM/DShot to your 4 ESCs
SPI1/2/3 — this is your IMU connection
USART1-6 / UART4-5 — this is your ELRS receiver connection
USB OTG FS (not the HS one) — this is your flashing port
ADC1-3 — only relevant if you add the optional current sense later
Power management section (VDD, VDDA, POR/PDR, reset & clock control) — this is what your Phase 1 decoupling caps actually connect to

claude is great subscribe.

umm we have quite good amount of memory



now  i have completed the data sheet and now i am confident to start. and i also found a flaw in the look that it dont count time exactly, there is errors in lookout, app i am doing this for morning 11 am and rn its 5pm, and it only counted my time.



this is not a small gap this is real things, my hrs are getting wasted, definaltly gonna report this and get my time back, also all other kids might be facing the same problem, so i better report it.

now i am confident, enough to start the schematicts the real thing, now i ahev to find the refrance schematics for  STM32F405RGT6, cuzz i reallly need that thing. after that will go for other thinsg.

i finally found the refrance schematics. it took me soo much browsing.


also i wont lose my time again i am getting proofs
here is it.



so now i reead the refrance schematic and now i know what i haev to copy and what is dont have to. i will be starting with STM32F405RGTx then will assign pins, to global labels

building while vibing



idk why system suks everytime i open kicad.

ohh man KICAD just crashed i hope my data is saved init.

bro wjy i should have saved this is too bad.


rn i am in lose, i lost the build of schematics, also my system is on the edge it is lagging like hell, it is freezing, 
i was doing macondo to get a decent laptop, but now thats on hold cuzz of arcana , i want to get to the singapore, 

now then i dont have any option left, all i can doo i restart.

I am back at that point where i lost it. yeah i saved it this time, lol

i have fnaally made someting. idk why this took so much time but atlest i fugure it, now i am gonna speed i haev to complete my project before 25 to amke it to singapore.



2 more pins done



this is what i haev done soo far. i know this is vey slow, tommorrow i amgoona lock the hard in.



so i have done today work, today i get the things know and get the hand on experience tommorow  u will what i am gonna do, fahhh

and i added one mroe thing. 



here is how it looks in full pic



bye for today.
<p align="center">THE END</p>

### 07/07/2036

## TOPIC: making schematics

today i will be completeing the my main MCU, and planning to do atlest 5hr today.
lets see how it goes.

i am editing the symbol cuz few pins are not visible and i dont like that, idk why but i want every thing precise and perfect. idk why sob>



can u see the progress



not gonna stop until i complete the MCU

so i just completd one more item, and i go to referece schematics and i found i am doing wrong i have added the erong values to the C1,C2, i gave them 100pf but these are too much i need only 10pf.


also these where missing



solved 



added the Indicator light



so i had few confusion on the power VDD33, VBAT, and VDD33A that should i mane them all VDD33, but my mentor said no keep them saprate they have there own works which are sparate, like VDD33 will provids the normal 3.3v but the VDD33A provide by filtering by ferrite bead.

bro idk what to doo the KICAD is get freez again n again.

bruh just found the the biggest blunder i did last night. 
i connected this 



with PA pins btu the was gonna get on PC pins.
here



now i need to solve this blunder, this si nto hard to solve but this is good i found this early.

now its done:



i made this but idk if i did it right or wrong.



let me ask the grok about it :)

grok said nothing much wrong just placed wrong way.
so i corrected it



progress can be seen.

now gonna make all these:



SD card one, but i am afraid what this doesnt matcht the schemtics properly, i think my symbol is diff

here is how myn looks, 



theres



just verified it not a big deel myn will work fine too. 

now  the SD CARD is fully done



next is:



i did the USB C jsut now but idk if this right or wrong.



i will ask latter in the #hardware help, cuz grok is getting confused. LOL

so the next is



bruk i stucked, i need this component 

 but this is not avalible and after taking with AI and getting pissed nnow i am gonna do it myself

means gonna make it my slef and new sybol for ME6231A33PG

now i have to make the symbol but idk how to make it, i will be my first time
i not able to figure it out, i think i should just watch a youtube tutorial.

broooooooooooooooo
i finally did it.



I think i have done something wrong, the pins are not connecting with wires. idk why.

bro finallt done this took me more then 1.5 hrs but atlest at the end i did it,



SO THIS IS END OF SECOND DAY JOURNAL.

bye for today.
<p align="center">THE END</p>

### 06/07/2036

## TOPIC: Doing ICM-20602

figuring out the pinouts.



nto able to find the data sheets for the ICM-20602.

ohh just find out.

now gonna read it, i will only read few parts, that are imp not all of em, i read all the for STM and regret it total waste of time, just learnt few concepts.

mhmhmhmhm
i  need to must make these thngs to make it stable and auto pilot.


Ok now i have all enough to get strated with ICM-20602. next is too find the refrance schematics to make sure its will work fine and dont make noise

found this in the KICAD, it is what i want but the pins are missing i think soo, maybe they are hidden.



the KICAD symbols of the ICM-20602 was a bit wrong in the both KICAD and the refrance schematics but no worries i have correcte it, so myy ancestors wont have to struggle, LOL. i mean i have redisign the whole symbol to match same as the refrance one.

bro i messed up the pins are not connectinf, i think i did set it right way

finally bro did it, this is hell i dont have option else then this except to use standard symbol, and i cant use it cuzz i want to fully match the schemtics and this will help me figure out things latter.

now all pins connect with wires

 

i am finally done with ICM-20602 this shit, actully this is not shit that refrance sch was, idk who tf made that there was soo many mistakes. i had to solve them that took soo long. 

but altelst at the end i did it.



bro next goona take even more time.

this goona be complete setup of 2-3 components that will work with moter so every mototr will have its own this setup, this what my mentors guide says:



bruh next Phase looks really hard


my mentor give datasheet that is in chinese how the hell i am goona translate it> metors sucks sometimes

found the right one in english:


<p align="center">THE END</p>

### 09/07/2036

## TOPIC:pahse 3 three hardest part

so last day its was  very bad day, i only did 2.5 hrs but i need to do the 10hrs per day, but anyway today we are goona do the phase 3:



why the it is too hard to find the perfect symbol, bro this sucks, the symbol i found is diff from the schemtics one

bro i found but i cant download it idk why it is on JLCPCB for eaasyday but it is not downloading and i also cant  fidn anywhere else.



maybe i should make my own by replicaating it.
 so yes i am goinfto make my own. wish me GL

SO FAR SO GOOD 


FINALLY DID IT MAN


i ma feeling pround now, cuz when i go span for this symbol they siad they will make me one but for 29$, and i made it myslef, ayayayyaya

but the most dificult thing still remins, the FOOTPRINT  and i never mmade it before. this gonna eb hard

it is too confusing to make the the footpritn i dk what to do maybe i will watch the toutorial:

bro its tooo hard. fahhhhhhhhhhhhhhhhhhhhhhhhhhh

i think i am doing something, not sure if this is right or wrong but still doing it.


bro why is this tooo hard, i ahev to take care of every mm and after more then 30 min i only did right side and i am not even sure if it is right or wrong



bro finally this is perfect now



finally completed
just numbering left for padds



completed



I DID SOME SCH WORK AND 1 ITEM IS DONE, THIS IS THE SYMBOL I GRINDED FOR:



i wonder why the hack the kicad symbols and the refrace schemtics symbols are no the same shpae, it tok t much tme to verify that pins are correct the the symbol is correct or not.



went to the break for 2hrs,now i am back fully charged, not goona sleep until complete this phase.

i really needa new laptop, form morning the KICAd have crashed more then 4 times, this is bad, it is slowing me down.

I DID some work, it was so confusing referance schematics that it took me sooo much time and still idk so many things init, and this is the best datasheet i found, there is one item idk what is it, and i havent added it yet, first i will confirm it then i will add it.



this is where i am rn, sub



fahhhhh, idk waana drink coffee anymore, sooo



i have completed the 90& of the 1st item of this phase, i still have confusion on the few lebals and components. who made this refrance schemtics must me crazy.

this is how myn looks rn:



this thing have serious effort of me, i made sybols and footprints, it must be right now.

i have done areally good, job, what i made in schematis is correct and i have verified it, the only thing i am missing now is the C and R values idk what values ot give them, and the refrace schemaitcs dont have them either.

finally it is almost done, one of the mot difficult things will be ending soon, and u cant imagine, how much my head hurts, cuz its 2am at night, fahhhh

its  now fully done, there no item in PHASe 2 thar is icomplete, everything is done. 





THANK GOD THIS IS DONE OR I WILL BE DEAD FRRR, 

i cant even explain, my condition rn, my eyes are full red rn and my head and back is paining hard, 

BUT I THINK IT IS WORTH IT:



<p align="center">THE END</p>

### 10/07/2036

## TOPIC: phase 4

so last day i completed the phase 3 and now i am gonna move to the phase 4.

organized the schematics a lil bit.



pahse 4 is a bit confusing, altough i have done this thing befre but it is locked in my subconscious memory, lol. 



ohh dman man htere are websites where if need any refrance schematcs we have to upload 4-5 docs to get that, alsolute shit

my lap is getting freez again and again. this is soo frustrating, 

i have almost finshed the phase 4, only batter connection left, its wasnt that hard how it looks it was just confusing.



arranged them so it wont looks mess



so i have completed the phase 4 now the only phase 5 left then ERC and then PCB and DRC



so now i cant find the, MAX7456 / AT7456 KICAD symbols and its refrance schematics

, so i ahev found the symbol but it in the someones repo so i need to clone the repo or download that file. SOB

got it



bro why tf is this shit too expensive, is it made of gold, damn this is shit i will stick with cheaper verionAT7456E



yoo man i was stressing for nothing, after some research i get to now that both MAX7456EUI+ and AT7456E are the same just clone to each other, so they have same KICAD symbol, and footprint and the the refrance schemaatics is also same for both of em.

OSD Completed:



also i have coloured the conntion of the ccompoents to the STm so if anyone wants to recreate this he will eb able to do it easily.





looks even better now.



there where some wrong connections in the OSD i have corrected them , and also did the USB-C 16pin





i added the USB C so it will be easy to flash the firmwre but now i get to know that STM32F405RGTx have specific pins for USB we canot reman as wee need and the that pins are alredy in the use of ESC pins. 

i think i should remove the USB C and stay on SW headers. 

so i was doing the BMP280 and i get confused on the pins that will be connected to the our STM32F405RGTx so i asked it to ai, PLZZ dont cut too much time, thanks. 

idk why i just pulled up with the help of AI, but i hope this is correct.**HI**



it was wrong, 



also there is no fast pins left on our MCU so i will be connecting its pins will rendom available pins.

Soo colorful



so the schemmatics is now done, i think this is it for schematics, we have everything to that will make drone fly.

its time for ERc lets see what hellish errors we got.

not much but not less eithr.



brouh i i have soo many messes in the schematics, and rn i cant find the refrance schematics.

damn man i speant 30min searing for pin connection but at the the end it was GND. FAHHHHHHHHHHHHH

i am using AI to solve a error plzz, consider this a nothing. 

ohh man playop is hanginn 

the kind of shit i am listening to keep my self swake.



the error where not that hard just needed to chnage the pin type form input to output and passive, now only 5 error left, i think i should solve them before i sleep.

yes i shoould.



now only one error left

damn man stuck on the last error 



SO this is it for today.

bye

bye for today.
<p align="center">THE END</p>

### 11/07/2036

## TOPIC: finshing the schemtics and solveing all error and moving to MCB.

so last day i completd the schematic, and was solveing the error but 1 error remains, and its a bit confusing.

now bro everything is done in schematics all ERC error are gone also there where some hidden error is the warining i have solved them too, so next i will be going to assign the footpints to the all components.

bro i messed up on battery connections, i used JST that is for low currents but i didnt know that for drones we need XT60PW-M to handel that much current.

also why tf battery are soo halla expensive

corrected the Battery conection.



i am, getting so frustrated rn, what the hell is with my laptop the symbol i made and its footprint was lost then i had to find, also soo many compoenents are confusing its getting to hard step by step, i am really losing

now i ahev to make a acoount to get open source footprint. seriously

so i ahev added 3model to the footprints not to all of them but few. i stoed cuz i found few mistakes that i have to solve before i move to anything else. also i havent added the MOSSFET footprints yet cuzz i didnt found  any, this ill be bad.



the only symbols left now is this



also i maybe have to redesign its symbol cuzz according tp google ur symbol must be same as footpint ur chosing but our are diff cuzz i didnt found the correct symbols

my brain is not brianing, cuz of these shitty MOSSFET, this shit is widely being used in drone but it dont have exact symbol and footprints, total shit.

i am opening that github guy schematics to see what symbol and footprints he is using .

bro what the hack that repo guy did to this, looks more like a creepy insect then PCB





bro this schemtics dont haev the things that i need, idk what is that but that is not what i am looking for, total waste of time.

oh bro hes verion is right an we i am very close i just need to extract the footprint from here, all other things are correct on my end, i was stressing fot nothing;
he is using same lebals as i 



OHH man finally got the footprint; Diodes_PowerDI3333-8 in package son

this is not a normal man look how badass he is , soo professional

i wonder how much time took hin to do this



u what, my laptop is too weird if any app stops responding i trys to restart the app by task amnager but task manager also stops responding, heelish hell

just completed all the footprints now the next part is my favrouit THE ROUTING part, i love this.

broooooo

this does not look good>



idk why but it dont, even thothat repo man had the same symbols but i think i missed something there..

now idk what design i should take for PCB like a small square or a rectangular, i think rectangular will be better, but still i will reserch on it.

how much i searched the square one is better, but will still add the small req in it, soo it will beeasy to route.
 i made an rough one , to see if it fits ir not and it is fitting perfectly in 50X50

i have to make new design where all components will setell the best way.



i made this but idk ehy it is not working i rechecked it but still not working

now i have very good design but it is not workking, idk why         SOB 

yayayyayayayayay
finally



i am placinf components very slowly and precisely, cud i dont wan tany mess i will take time but make it best

first phase done







hey i had a SD in the shematics i think i should delete it cuz i dont find any crusial use case

bro i deleted the SD card got this in return gify, tf



can u see the amount of work done, and still going ggggggggsssssssssssssssss



bye for today.
<p align="center">THE END</p>

### 012/07/2036

## TOPIC: trace routing

last day i finalized the schematics and today i am will be routhing.

i am arranging the set of components as accurate as possible to keep drone stabel and so barometer can work perfectly. 

so i will be placcing complete 4 esc channels on back and other will be on from 

for the channels i have to bee soo precise so it will be easy to route them, i have done 1 channel now i will place other on it anf then just flip then this i will have all 5 channels in same accurate structure.



exactly as we wanted ayyayayayay





i was think of replacing the JST with the test pads if these can flash as JST. cuzz JST is taking so much space.

gonna add the test points footprints, this these wont take much space and they will be waightless. 
WINWIN
so i am going to use the test pads here how they looks



Much better then before




goiing soo good soo far yayayayyaya




the method i am using for compoenents takes but work soo well, almost 100% accurate



finally did it:





bro i am still confused about our mossets, idk if they ar ecorrect or not. i have a bad feeling so i am checking it one last time.

ok so my biggest stress is gone, i had very confusion on the MOSSETS but now it clered, but no i have to change few things in the schematics and PCB both, then routing,
this project will be hardest thing i ever build, 

finally the stress hthing is now gone. yyayyayaya



bro i locked the components now i dont know how to unlock them.



BRO KICAD crashed and my component placment rest, fahhhhhhhhhh

i did all the placment again, so its will be easy to route. soo alll ESC channel on B.cu and all other components are on F.cu



also i have adde dhte barometer in the B.cu center so it will be better in reading the data.



moving to the route tracing, but before that will be adding the layers, so i am going with 4 layer PCB.

here is how it will be



idk, if i am forgeting how to add the layers or KICAD have been changed

bye for today.
<p align="center">THE END</p>

### 13/07/2036

## TOPIC: routing

 todays goal is to complete the routhing and all there PCB things then do the CAD for the drone and then submit the project before i sleep, or i cant sleep.
 and today i wont be journaling much cuzz i need to lock in.

 BTW check out how cool it looks.

 
 
bro oly one ESC channel got soo much time and there is still 3 more to go, and they wil be even harder cuz they have components at there back too



tbh its looks cool right?



idk how to explain, but this is serious i was roting normallay and internet was gone, i cant explain how hard things i did and the sad thing it didnt get recored no a single min, and now internet is back so i am writing this. just see this, i put more then 5hrs on single ESC channel and after that it is completed. it was tooo hard.



 routing was almost conmpleted just rined the DRC and the KICAd crashed, i hope progess is saved.

 





finally the PCB is completed. all the tarces are routed now and almost all error and wrings are gone, now kuct need to complete the GRC< 

its looks sooo coool, ooohhhhhhhhh my yesssssssssssssss





all the pcb work is done now, 

my internet was gone so i was not able to journal, but i kept working and completed the PCB and now doing the CAD.

### 14/07/2036

## TOPIC: CAD 

i think we need bigger props.



so i am not making all in one vody this will be in parts the main base and 4 arms, that why i am also adding the stabilizer for better flights, so it wont woble much.



so i ma switching from lapse to hacktime, setup in freecad, cuzz lapse sucks.

finally complted the cad also the internet is back and stable now, i used hacktime for freecad, cuz lapse is not working , so the next i will be woking on firmware, even i am not gonna build completed, cuz i will do that when i will get everything in my hands, so rn it will be more like a skeleton

check this out



about the frimware i dont have to write the frimware from scratch, there are alredy frist class porved out there online,i just need to configure them.

so this gonna be my last journal, i have completed the project and no i just need to submit it.
one last thing. 
i have used ai while recording just cuz i difnt had any ooption left so i used it, dont detuct too much time.

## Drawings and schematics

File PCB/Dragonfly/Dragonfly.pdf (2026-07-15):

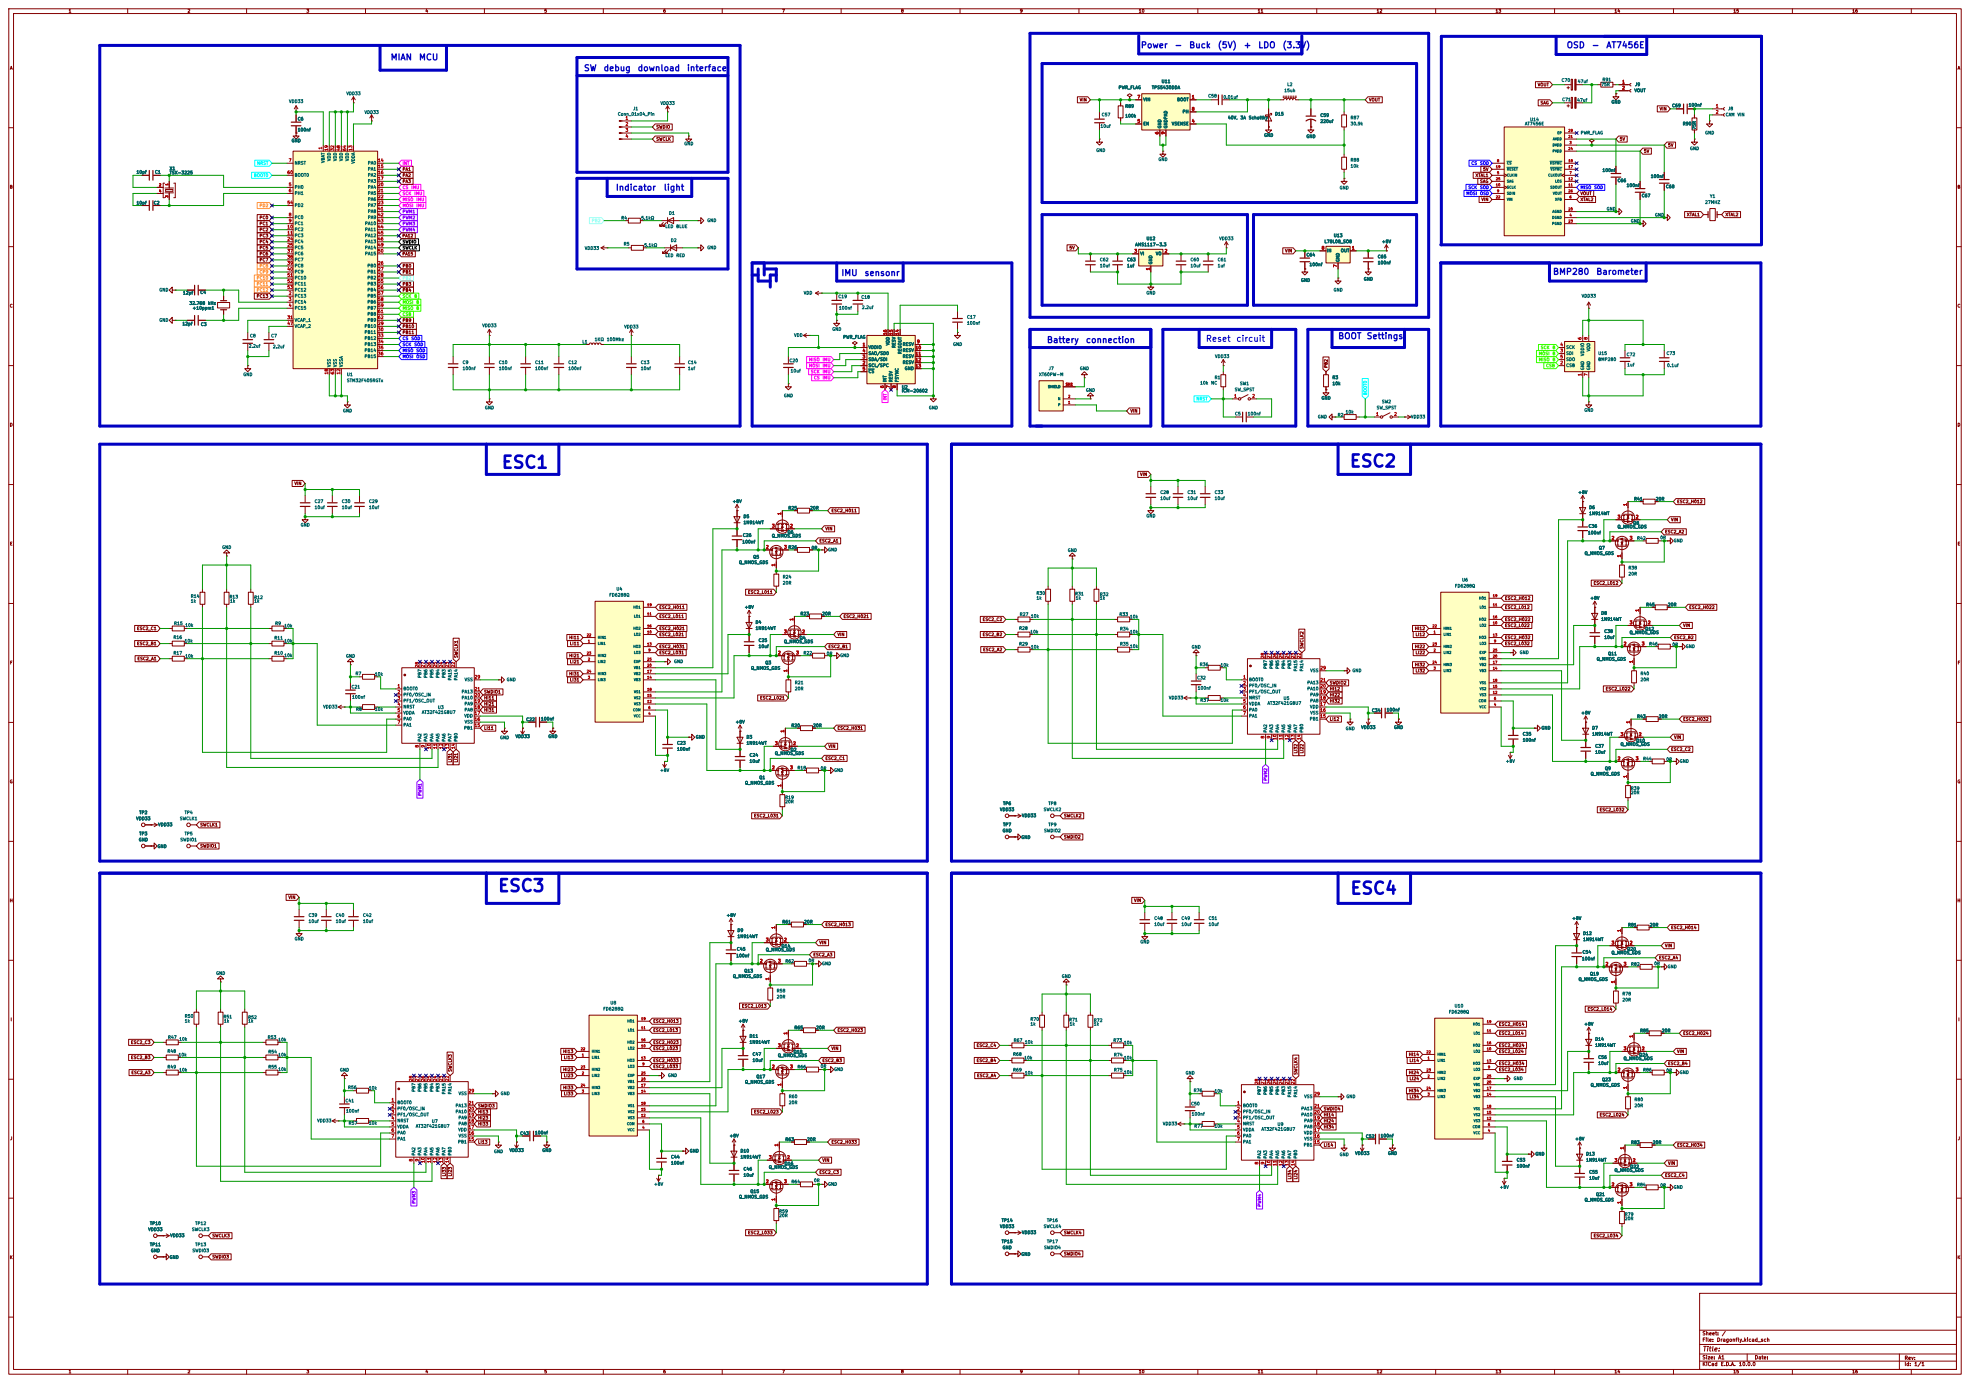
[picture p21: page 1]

Power - Buck (5V) + LDO (3.3V)

OSD - AT7456E

SW debug download interface

8 RESV 9 RESV 10 RESV 11 RESV 12 GND

MISO IMU
SCK IMU MOSI IMU

Size: A1 | Rev:
KiCad E.D.A. 10.0.0 | Id: 1/1

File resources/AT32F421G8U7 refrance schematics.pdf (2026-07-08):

# USB

# BAROMETER

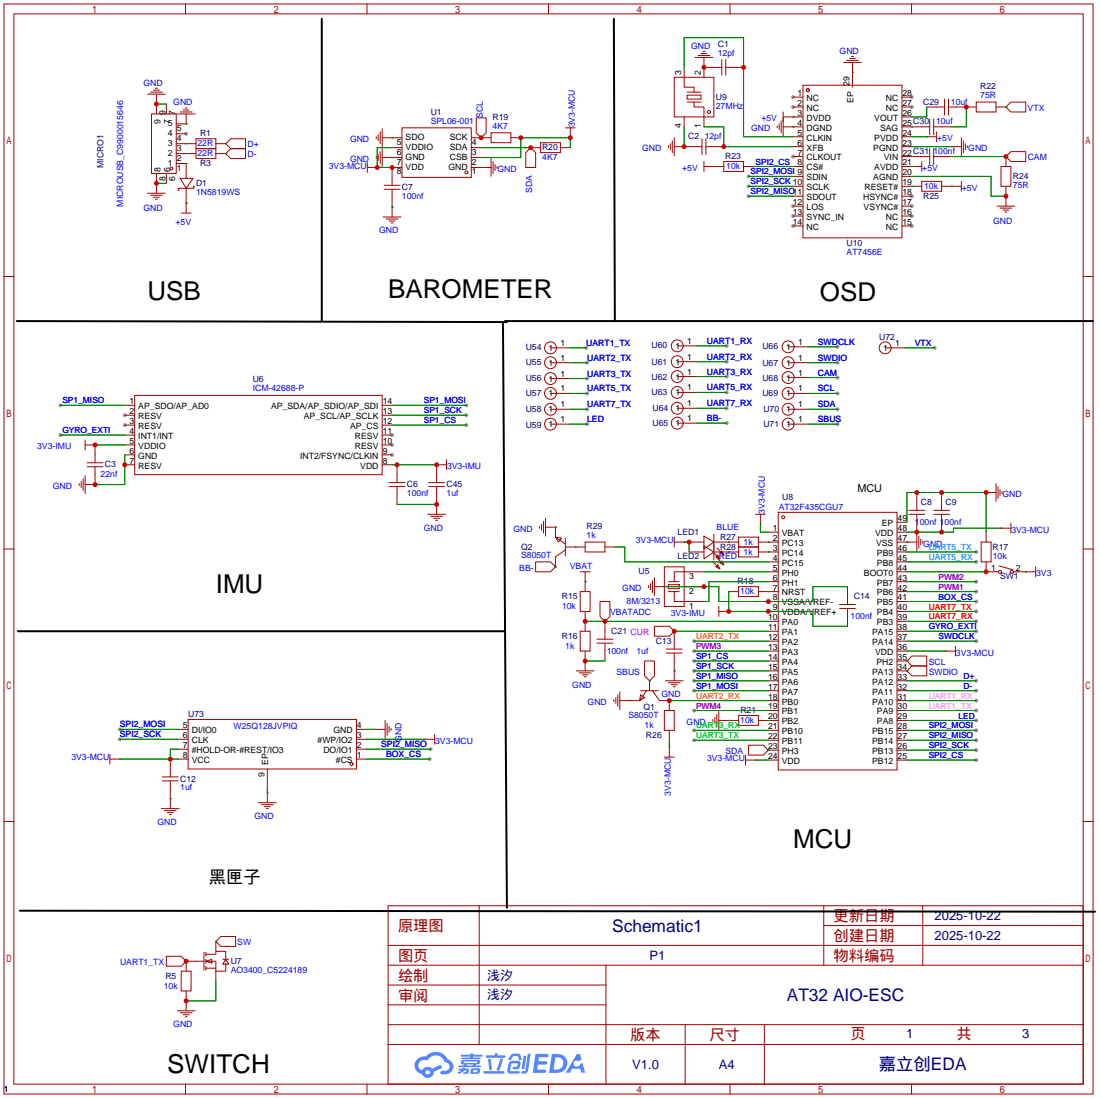
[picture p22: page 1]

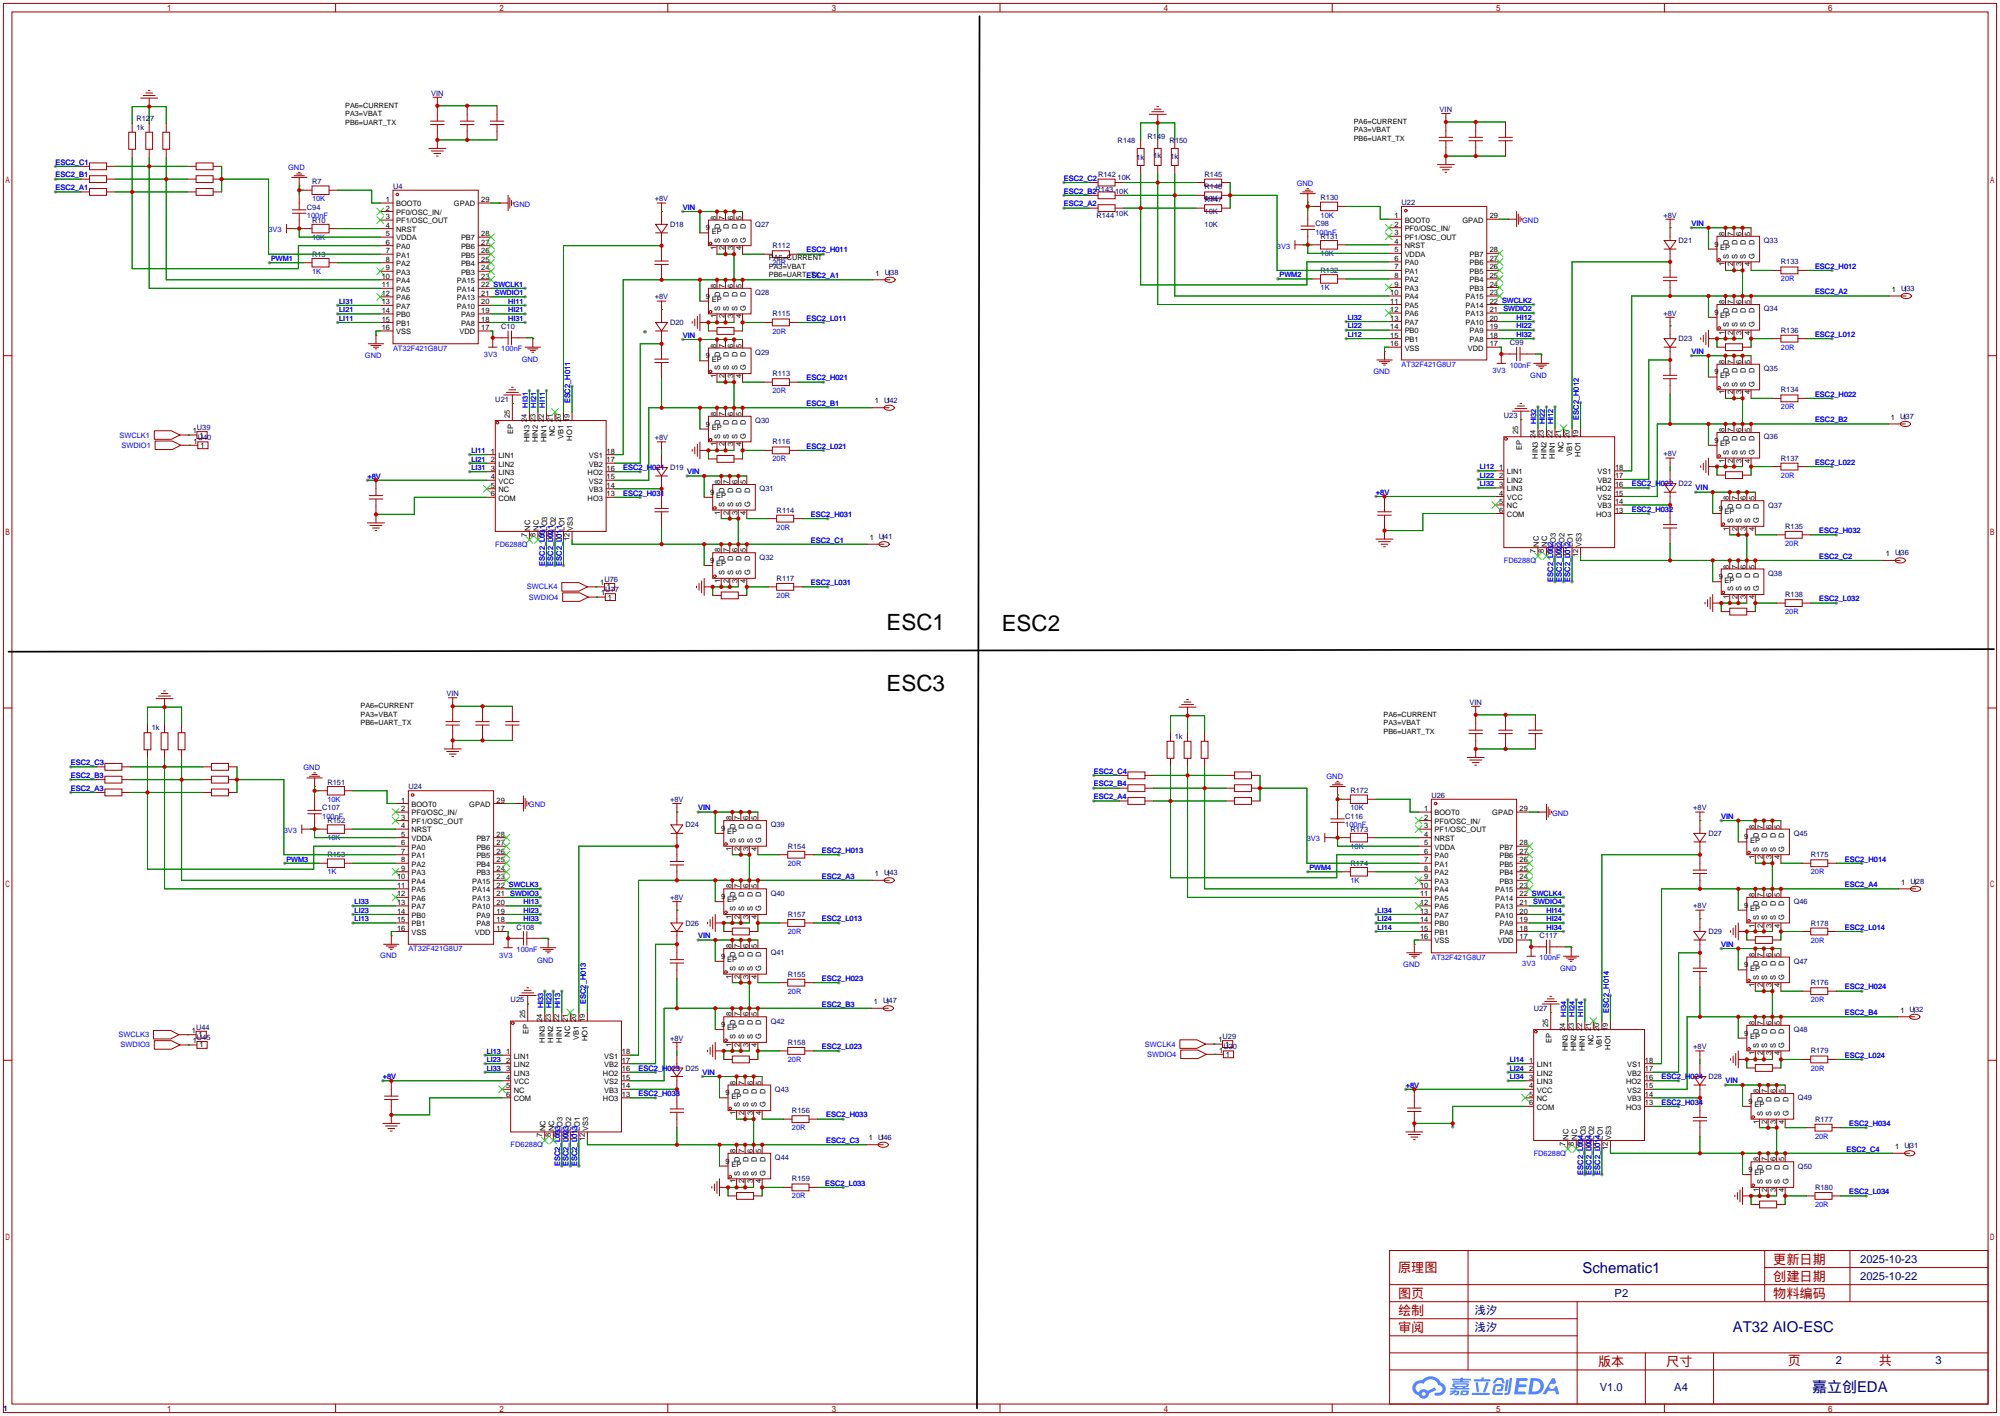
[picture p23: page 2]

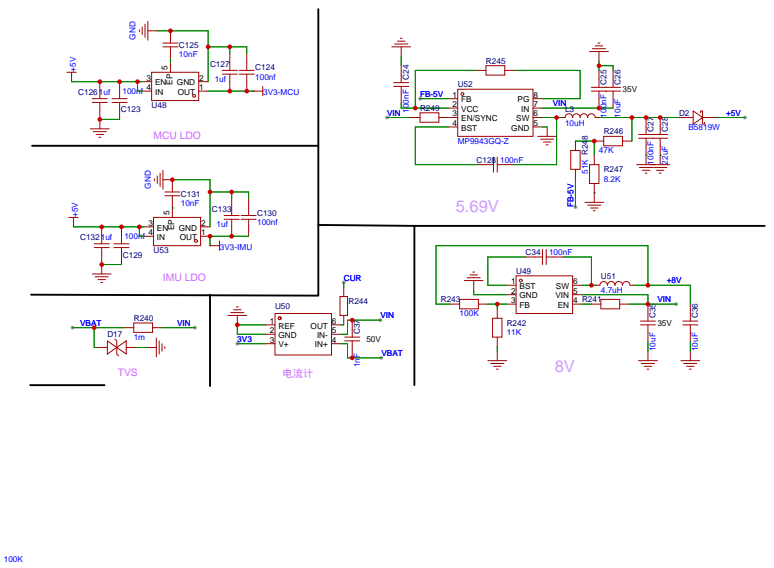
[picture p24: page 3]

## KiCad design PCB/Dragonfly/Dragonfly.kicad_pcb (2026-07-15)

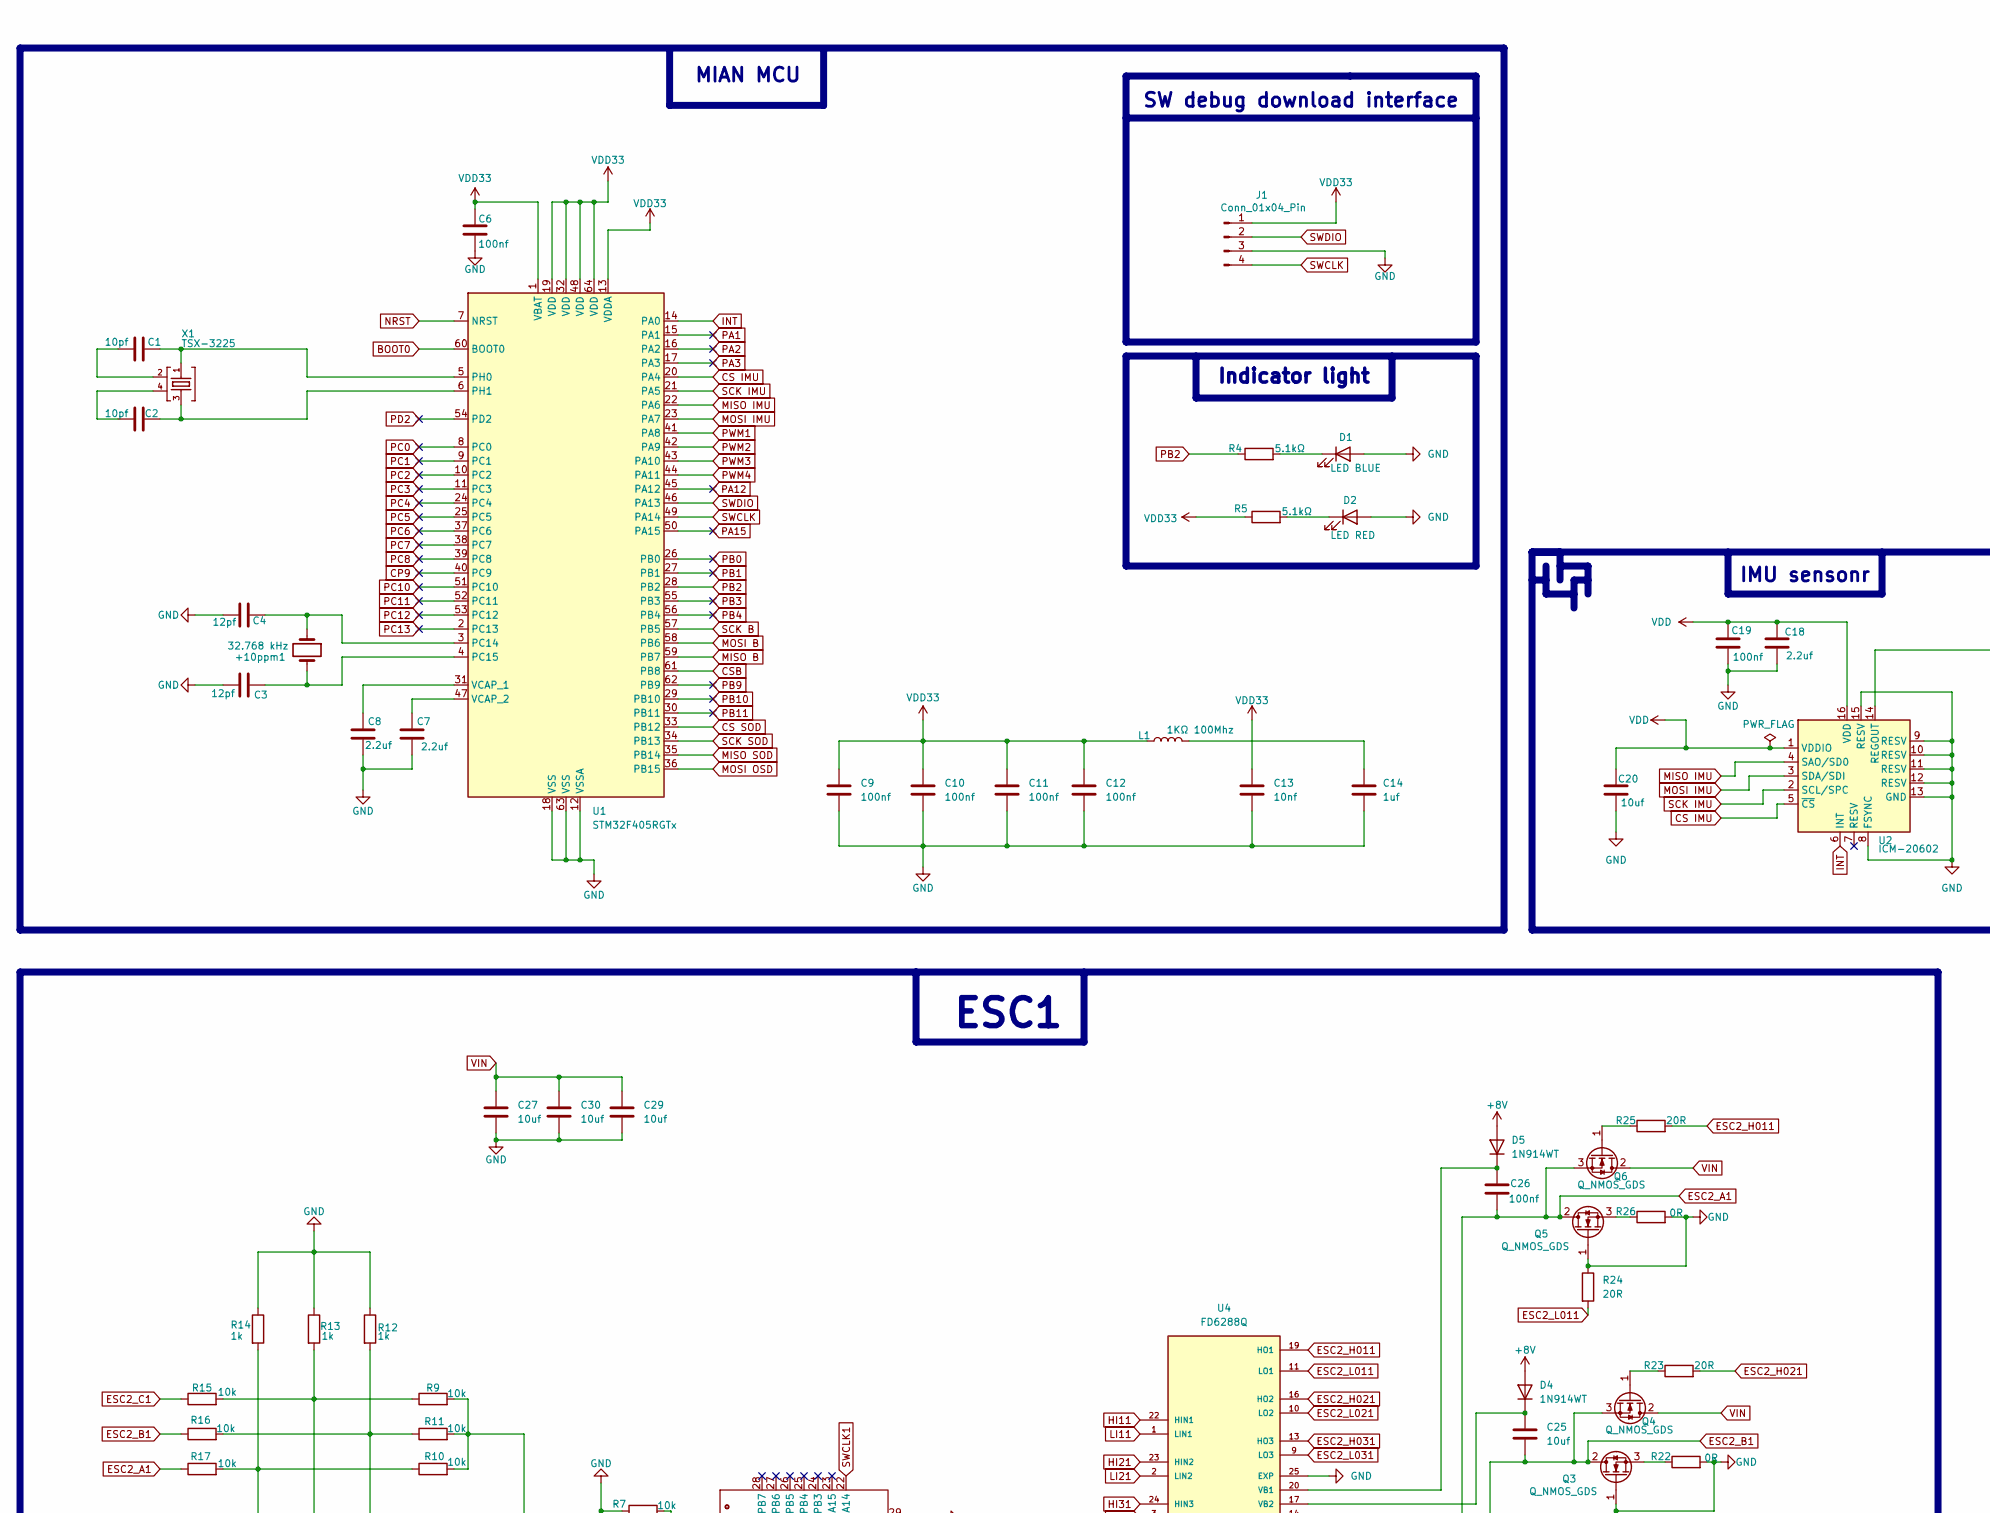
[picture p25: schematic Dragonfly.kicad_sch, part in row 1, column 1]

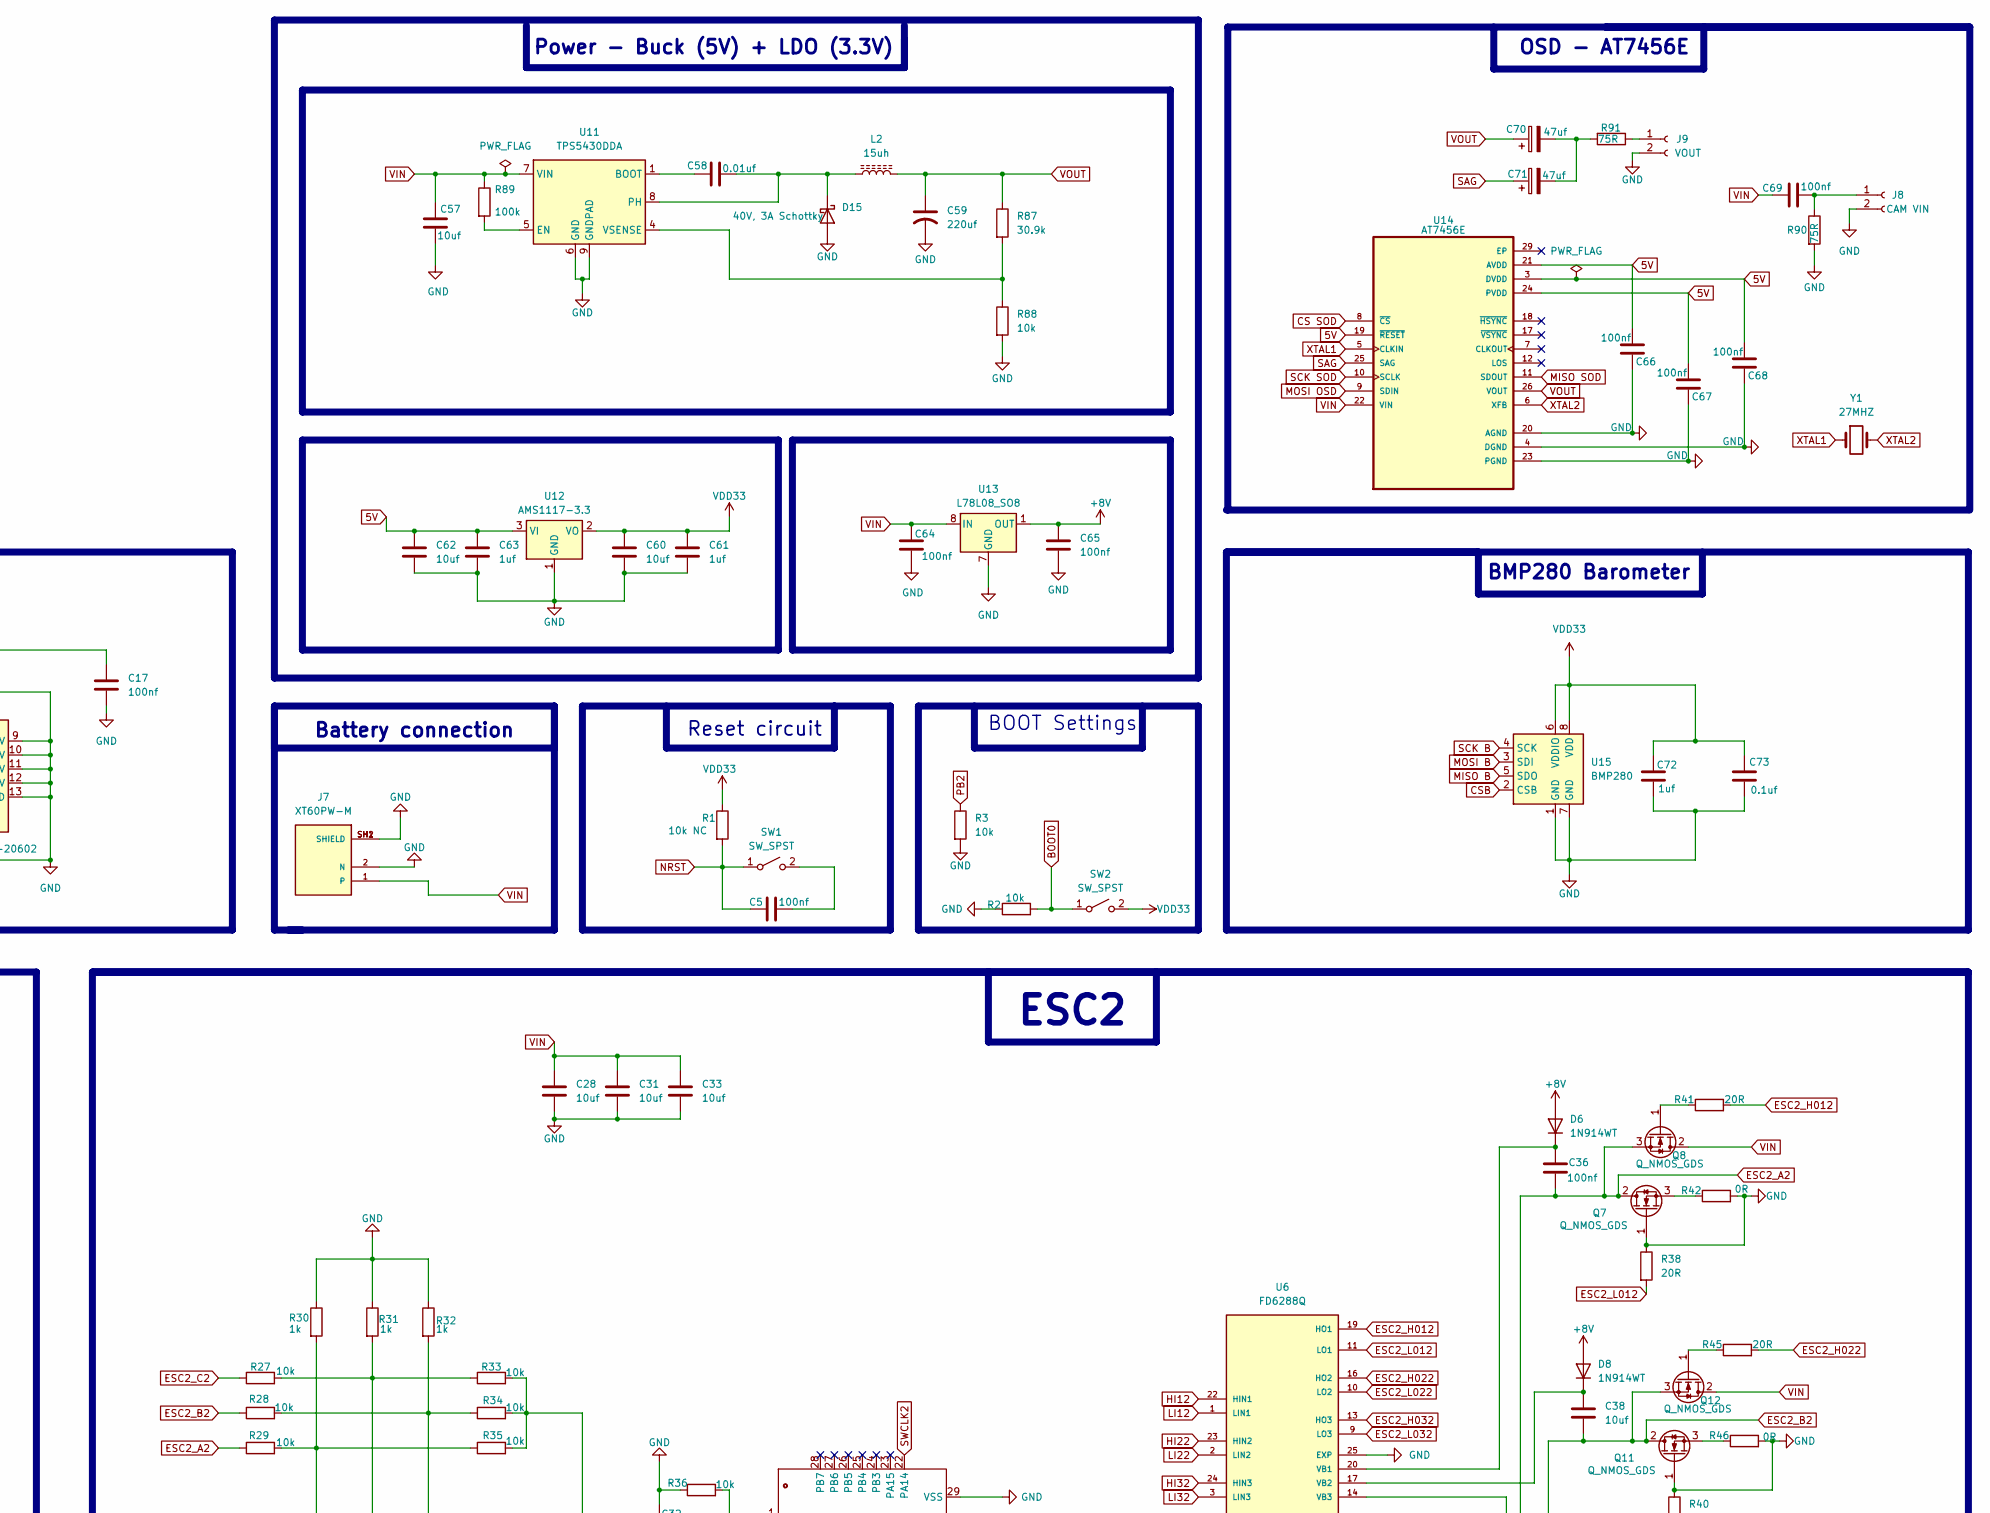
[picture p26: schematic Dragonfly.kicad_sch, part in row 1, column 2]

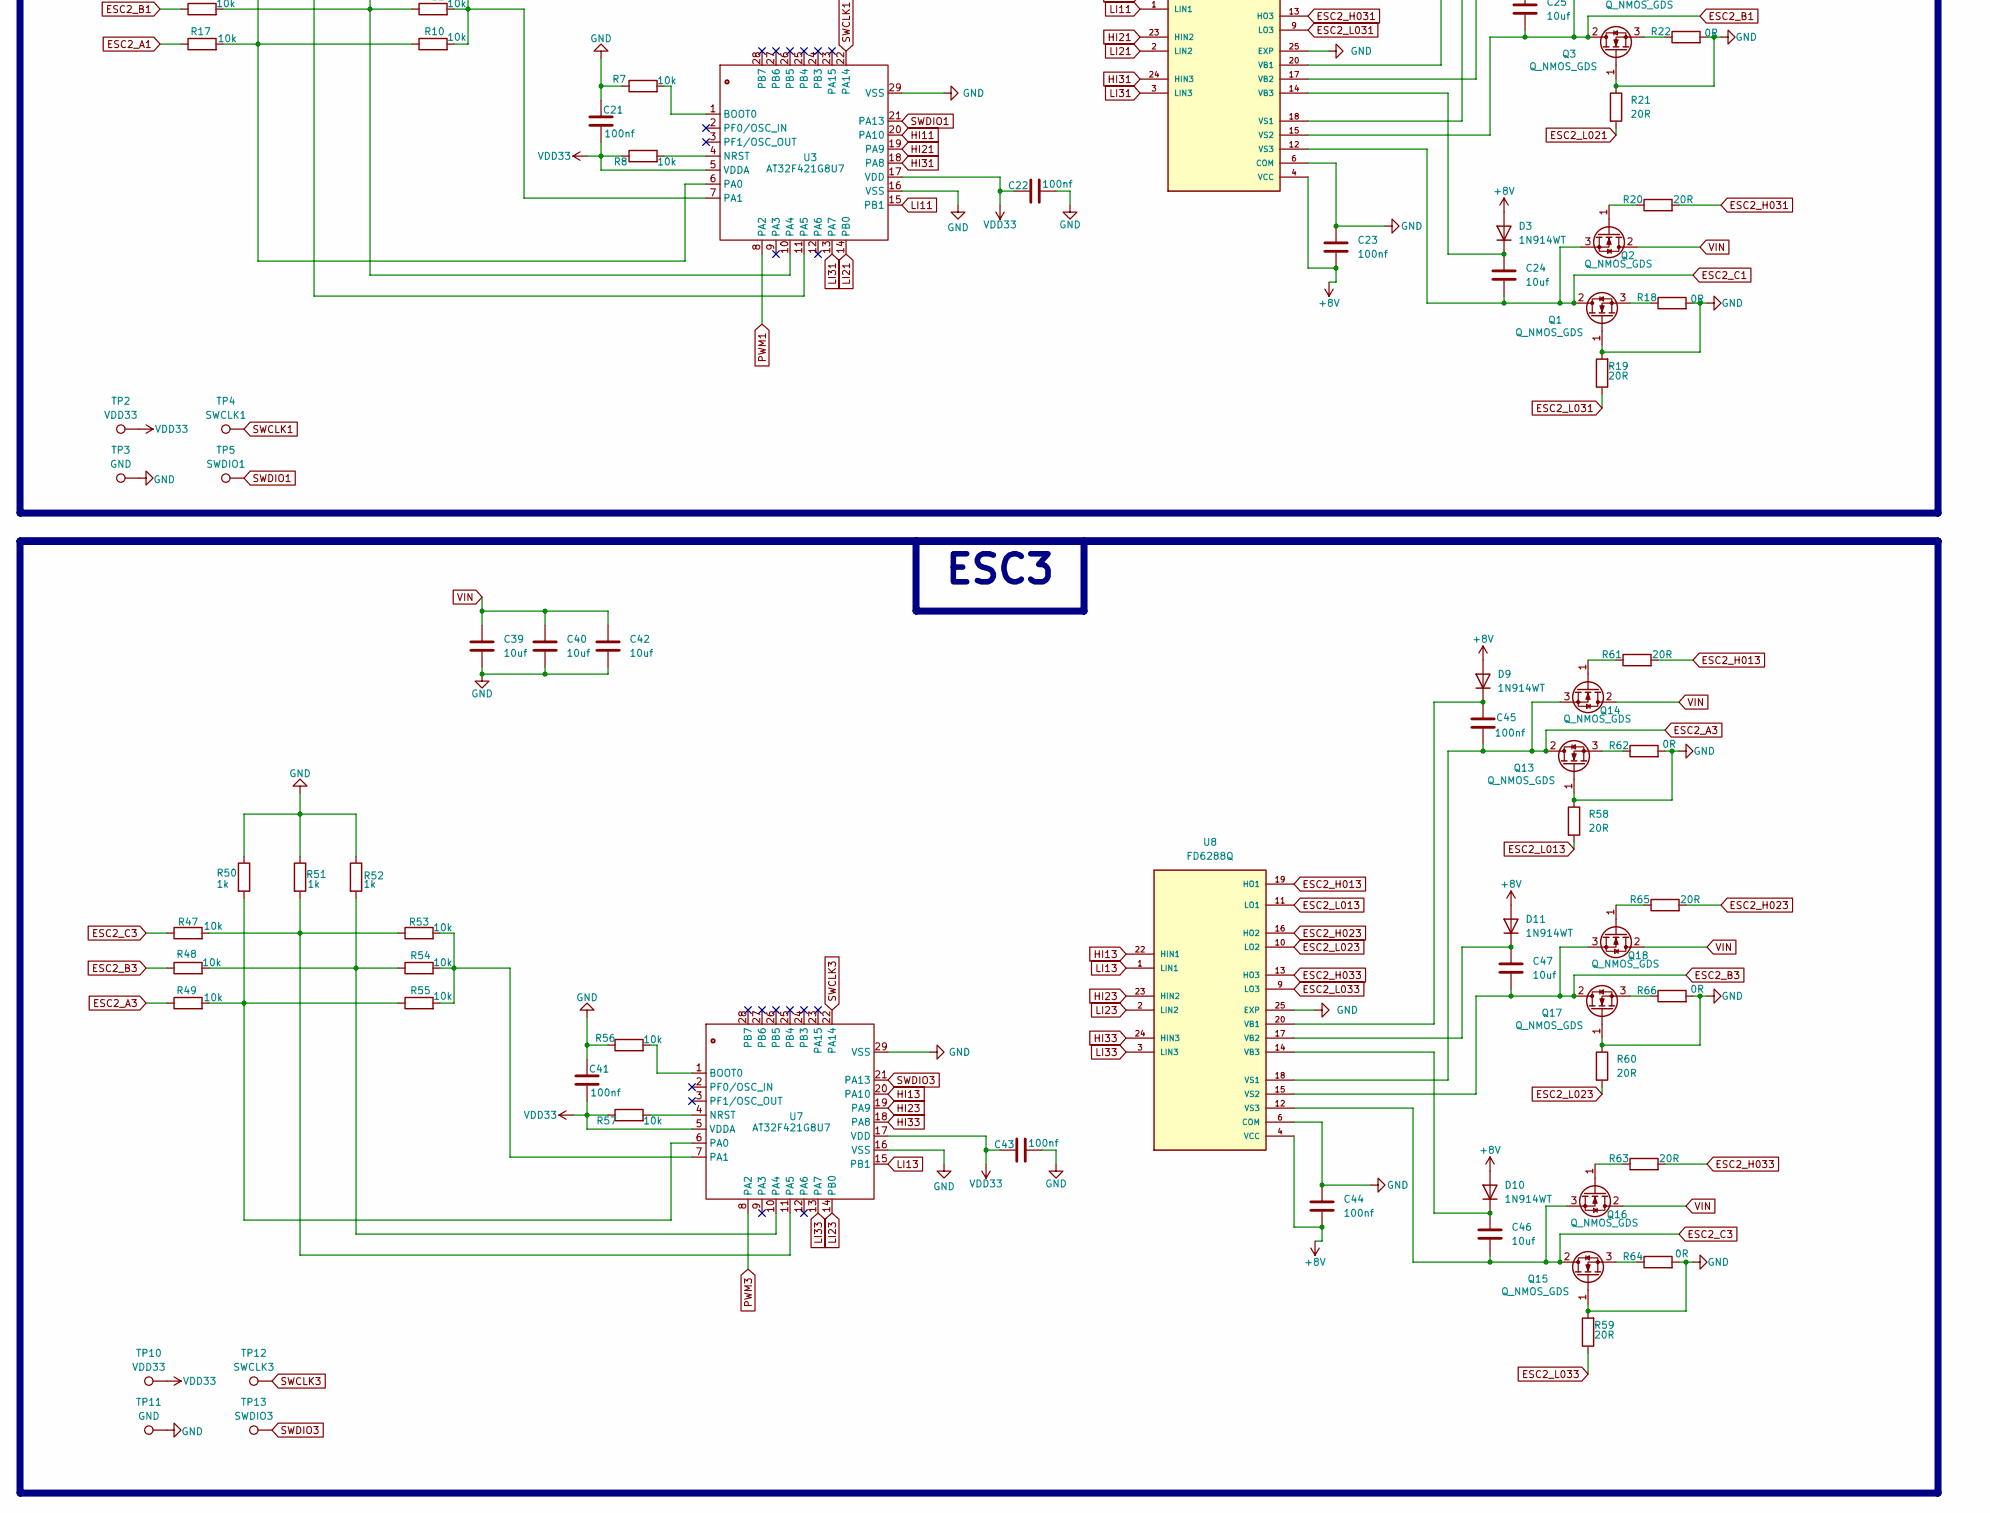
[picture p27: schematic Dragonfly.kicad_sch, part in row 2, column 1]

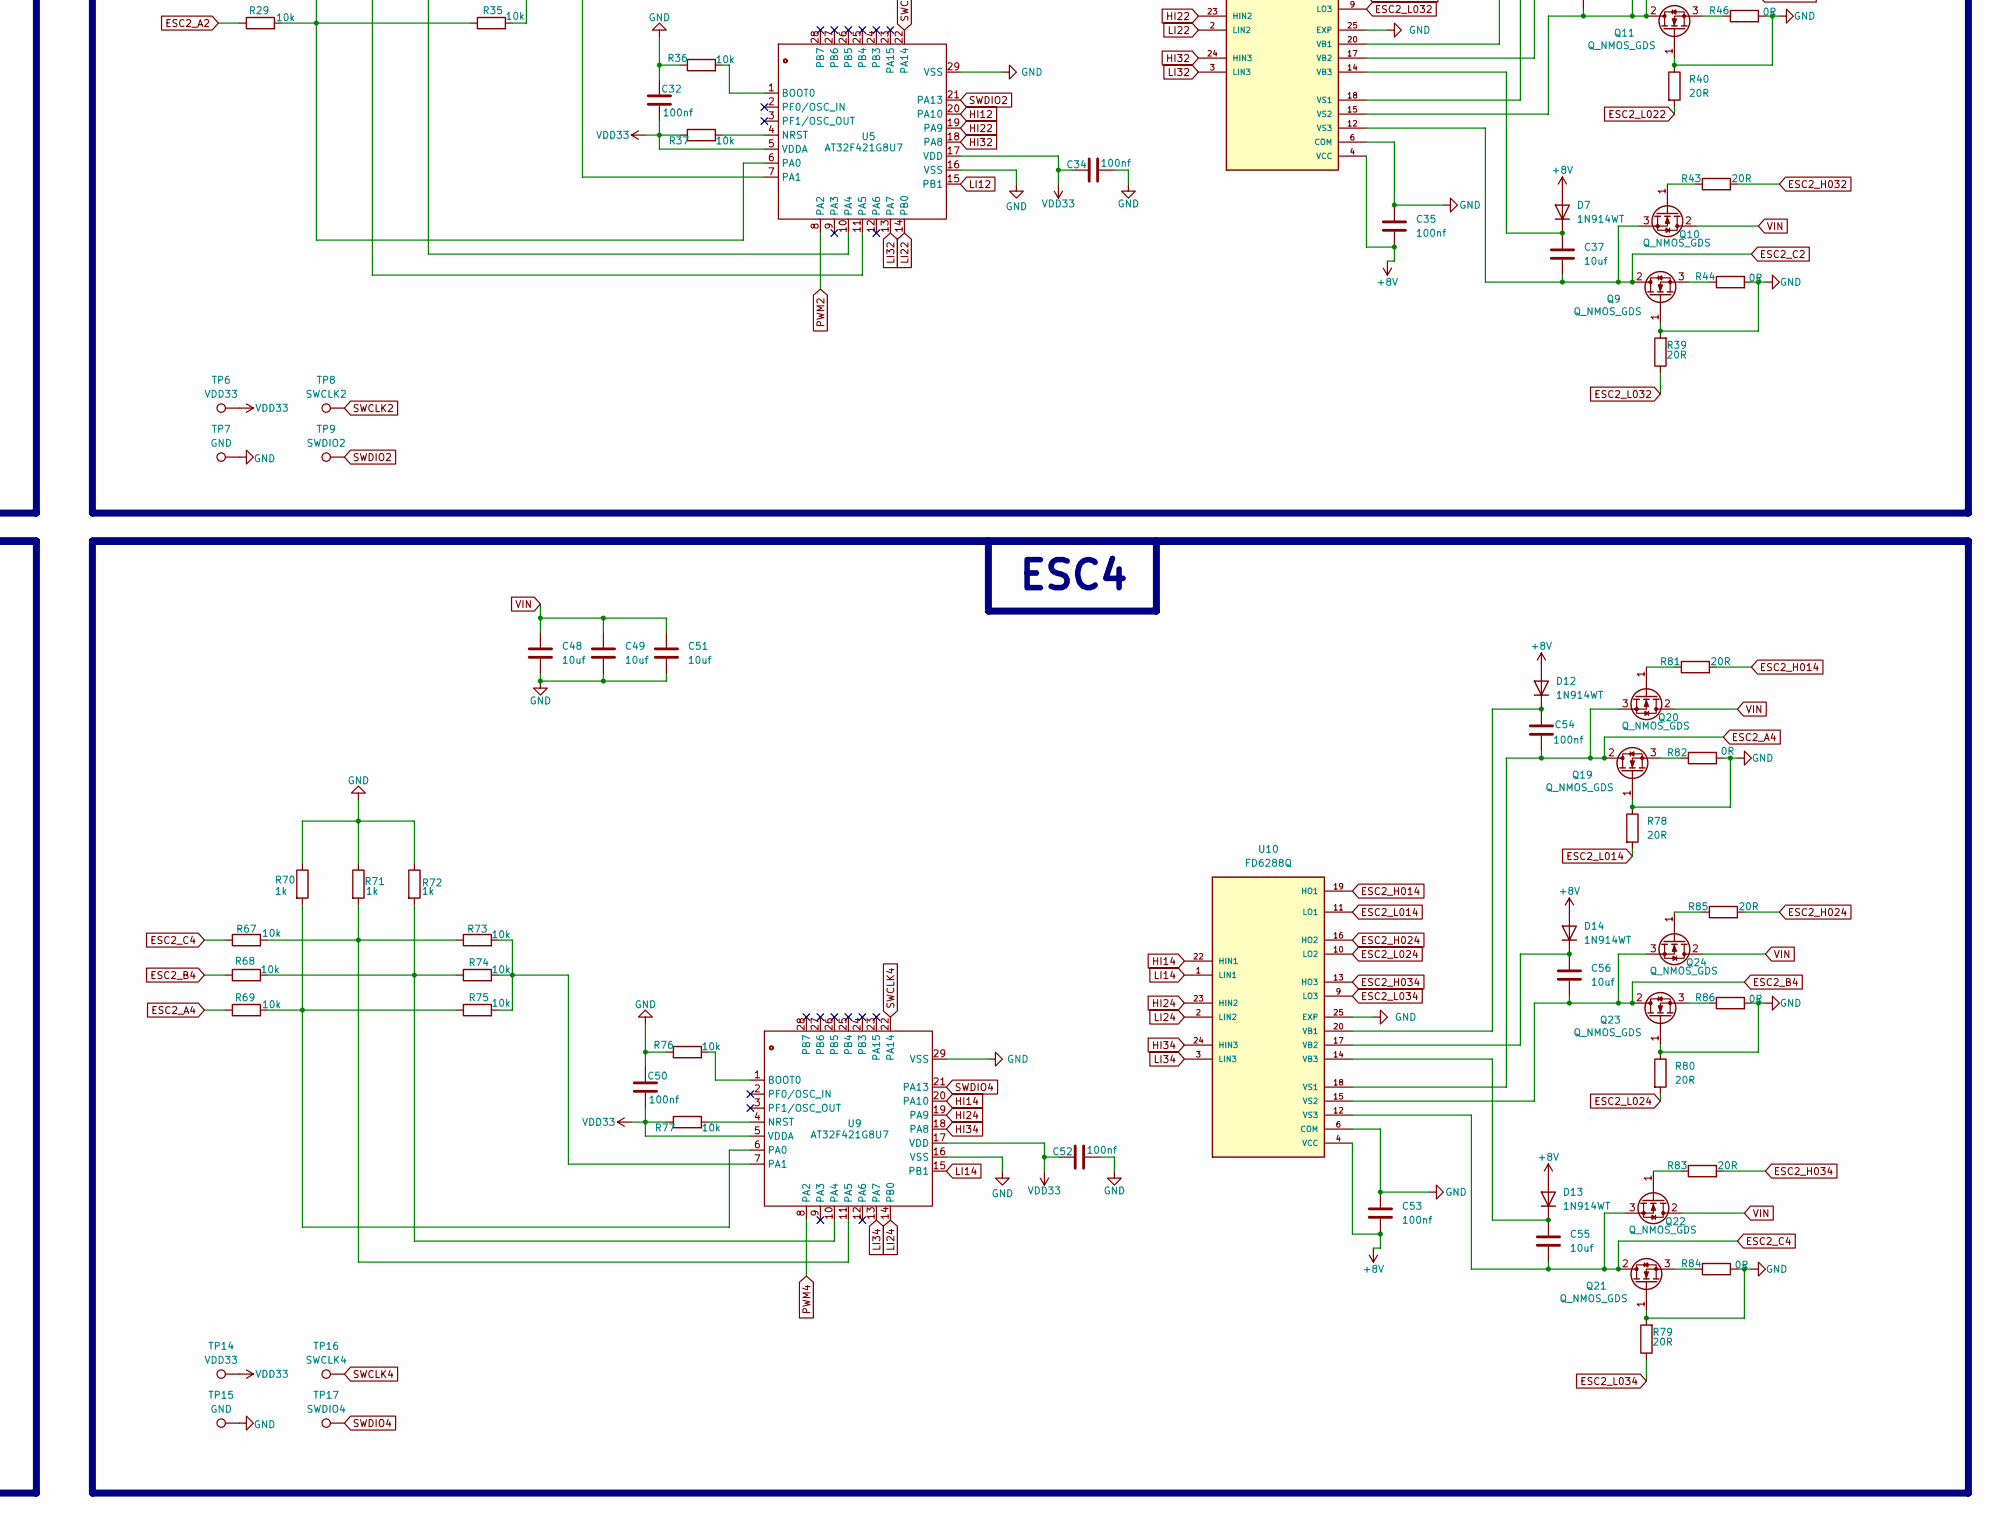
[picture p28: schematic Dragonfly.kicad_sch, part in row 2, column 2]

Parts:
+10ppm1: 32.768 kHz; Crystal_SMD_3225-4Pin_3.2x2.5mm
C1, C2: 10pf; C_0402_1005Metric
C3, C4: 12pf; C_0402_1005Metric
C5, C6, C9, C10, C11, C12, C17, C19, C21, C22, C23, C26, C32, C34, C35, C36, C41, C43, C44, C45, C50, C52, C53, C54, C64, C65, C66, C67, C68, C69: 100nf; C_0402_1005Metric
C7, C8, C18: 2.2uf; C_0402_1005Metric
C13: 10nf; C_0402_1005Metric
C14, C61, C63, C72: 1uf; C_0402_1005Metric
C20, C24, C25, C27, C28, C29, C30, C31, C33, C37, C38, C39, C40, C42, C46, C47, C48, C49, C51, C55, C56, C57, C60, C62: 10uf; C_0402_1005Metric
C58: 0.01uf; C_0402_1005Metric
C59: 220uf; CP_Elec_6.3x5.8
C70, C71: 47uf; C_0402_1005Metric
C73: 0.1uf; C_0402_1005Metric
D1: LED BLUE; LED_0201_0603Metric
D2: LED RED; LED_0201_0603Metric
D3, D4, D5, D6, D7, D8, D9, D10, D11, D12, D13, D14: 1N914WT; D_SOD-523
D15: 40V, 3A Schottky; D_SMC
J1: Conn_01x04_Pin; JST_EH_B4B-EH-A_1x04_P2.50mm_Vertical
J7: XT60PW-M; AMASS_XT60PW-M; PARTREV 1.2
J8: CAM VIN; JST_EH_B2B-EH-A_1x02_P2.50mm_Vertical
J9: VOUT; JST_EH_B2B-EH-A_1x02_P2.50mm_Vertical
L1: 1KΩ 100Mhz; L_0402_1005Metric
L2: 15uh; L_Wurth_WE-LQSH-4020
Q1, Q2, Q3, Q4, Q5, Q6, Q7, Q8, Q9, Q10, Q11, Q12, Q13, Q14, Q15, Q16, Q17, Q18, Q19, Q20, Q21, Q22, Q23, Q24: Q_NMOS_GDS; Diodes_PowerDI3333-8
R1: 10k NC; R_0402_1005Metric
R2, R3, R7, R8, R9, R10, R11, R15, R16, R17, R27, R28, R29, R33, R34, R35, R36, R37, R47, R48, R49, R53, R54, R55, R56, R57, R67, R68, R69, R73, R74, R75, R76, R77, R88: 10k; R_0402_1005Metric
R4, R5: 5.1kΩ; R_0402_1005Metric
R12, R13, R14, R30, R31, R32, R50, R51, R52, R70, R71, R72: 1k; R_0402_1005Metric
R18, R22, R26, R42, R44, R46, R62, R64, R66, R82, R84, R86: 0R; R_0402_1005Metric
R19, R20, R21, R23, R24, R25, R38, R39, R40, R41, R43, R45, R58, R59, R60, R61, R63, R65, R78, R79, R80, R81, R83, R85: 20R; R_0402_1005Metric
R87: 30.9k; R_0815_2038Metric
R89: 100k; R_0402_1005Metric
R90, R91: 75R; R_0402_1005Metric
SW1, SW2: SW_SPST; SW_Tactile_SPST_NO_Straight_CK_PTS636Sx25SMTRLFS
TP2, TP6, TP10, TP14: VDD33; TestPoint_Pad_D1.0mm
TP3, TP7, TP11, TP15: GND; TestPoint_Pad_D1.0mm
TP4: SWCLK1; TestPoint_Pad_D1.0mm
TP5: SWDIO1; TestPoint_Pad_D1.0mm
TP8: SWCLK2; TestPoint_Pad_D1.0mm
TP9: SWDIO2; TestPoint_Pad_D1.0mm
TP12: SWCLK3; TestPoint_Pad_D1.0mm
TP13: SWDIO3; TestPoint_Pad_D1.0mm
TP16: SWCLK4; TestPoint_Pad_D1.0mm
TP17: SWDIO4; TestPoint_Pad_D1.0mm
U1: STM32F405RGTx; LQFP-64_10x10mm_P0.5mm
U2: ICM-20602; LGA-16_3x3mm_P0.5mm_LayoutBorder3x5y
U3, U5, U7, U9: AT32F421G8U7
U4, U6, U8, U10: FD6288Q; QFN50P400X400X90-25N
U11: TPS5430DDA; TI_SO-PowerPAD-8_ThermalVias
U12: AMS1117-3.3; SOT-223-3_TabPin2
U13: L78L08_SO8; SOIC-8_3.9x4.9mm_P1.27mm
U14: AT7456E; SOP65P640X120-29N
U15: BMP280; Bosch_LGA-8_2x2.5mm_P0.65mm_ClockwisePinNumbering
X1: TSX-3225
Y1: 27MHZ; Crystal_SMD_3225-4Pin_3.2x2.5mm

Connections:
5V: C62.1, C63.1, C66.1, C67.1, C68.1, U12.3 (VI), U14.3 (DVDD), U14.19 (~RESET), U14.21 (AVDD), U14.24 (PVDD)
+8V: C23.2, C35.2, C44.2, C53.2, C65.1, D3.2 (A), D4.2 (A), D5.2 (A), D6.2 (A), D7.2 (A), D8.2 (A), D9.2 (A), D10.2 (A), D11.2 (A), D12.2 (A), D13.2 (A), D14.2 (A), U4.4 (VCC), U6.4 (VCC), U8.4 (VCC), U10.4 (VCC), U13.1 (OUT)
BOOT0: R2.2, SW2.1 (A), U1.60 (BOOT0)
CP9: U1.40 (PC9)
CS IMU: U1.20 (PA4), U2.5 (~CS)
CS SOD: U1.33 (PB12), U14.8 (~CS)
CSB: U1.61 (PB8), U15.2 (CSB)
ESC2_A1: C26.2, Q5.2 (D), Q6.3 (S), R17.1, U4.18 (VS1)
ESC2_A2: C36.2, Q7.2 (D), Q8.3 (S), R29.1, U6.18 (VS1)
ESC2_A3: C45.2, Q13.2 (D), Q14.3 (S), R49.1, U8.18 (VS1)
ESC2_A4: C54.2, Q19.2 (D), Q20.3 (S), R69.1, U10.18 (VS1)
ESC2_B1: C25.2, Q3.2 (D), Q4.3 (S), R16.1, U4.15 (VS2)
ESC2_B2: C38.2, Q11.2 (D), Q12.3 (S), R28.1, U6.15 (VS2)
ESC2_B3: C47.2, Q17.2 (D), Q18.3 (S), R48.1, U8.15 (VS2)
ESC2_B4: C56.2, Q23.2 (D), Q24.3 (S), R68.1, U10.15 (VS2)
ESC2_C1: C24.2, Q1.2 (D), Q2.3 (S), R15.1, U4.12 (VS3)
ESC2_C2: C37.2, Q9.2 (D), Q10.3 (S), R27.1, U6.12 (VS3)
ESC2_C3: C46.2, Q15.2 (D), Q16.3 (S), R47.1, U8.12 (VS3)
ESC2_C4: C55.2, Q21.2 (D), Q22.3 (S), R67.1, U10.12 (VS3)
ESC2_H011: R25.2, U4.19 (HO1)
ESC2_H012: R41.2, U6.19 (HO1)
ESC2_H013: R61.2, U8.19 (HO1)
ESC2_H014: R81.2, U10.19 (HO1)
ESC2_H021: R23.2, U4.16 (HO2)
ESC2_H022: R45.2, U6.16 (HO2)
ESC2_H023: R65.2, U8.16 (HO2)
ESC2_H024: R85.2, U10.16 (HO2)
ESC2_H031: R20.2, U4.13 (HO3)
ESC2_H032: R43.2, U6.13 (HO3)
ESC2_H033: R63.2, U8.13 (HO3)
ESC2_H034: R83.2, U10.13 (HO3)
ESC2_L011: R24.2, U4.11 (LO1)
ESC2_L012: R38.2, U6.11 (LO1)
ESC2_L013: R58.2, U8.11 (LO1)
ESC2_L014: R78.2, U10.11 (LO1)
ESC2_L021: R21.2, U4.10 (LO2)
ESC2_L022: R40.2, U6.10 (LO2)
ESC2_L023: R60.2, U8.10 (LO2)
ESC2_L024: R80.2, U10.10 (LO2)
ESC2_L031: R19.1, U4.9 (LO3)
ESC2_L032: R39.1, U6.9 (LO3)
ESC2_L033: R59.1, U8.9 (LO3)
ESC2_L034: R79.1, U10.9 (LO3)
GND: C3.2, C4.2, C6.2, C7.2, C8.2, C9.2, C10.2, C11.2, C12.2, C13.2, C14.2, C17.2, C18.2, C19.2, C20.2, C21.1, C22.2, C23.1, C27.2, C28.2, C29.2, C30.2, C31.2, C32.1, C33.2, C34.2, C35.1, C39.2, C40.2, C41.1, C42.2, C43.2, C44.1, C48.2, C49.2, C50.1, C51.2, C52.2, C53.1, C57.2, C59.2, C60.2, C61.2, C62.2, C63.2, C64.2, C65.2, C66.2, C67.2, C68.2, C72.2, C73.2, D1.2 (A), D2.2 (A), D15.2 (A), J1.3, J7.2 (N), J7.SH1 (SHIELD), J7.SH2 (SHIELD), J8.2, J9.2, Q1.1 (G), Q3.1 (G), Q5.1 (G), Q7.1 (G), Q9.1 (G), Q11.1 (G), Q13.1 (G), Q15.1 (G), Q17.1 (G), Q19.1 (G), Q21.1 (G), Q23.1 (G), R2.1, R3.2, R7.1, R12.1, R13.1, R14.1, R18.2, R19.2, R21.1, R22.2, R24.1, R26.2, R30.1, R31.1, R32.1, R36.1, R38.1, R39.2, R40.1, R42.2, R44.2, R46.2, R50.1, R51.1, R52.1, R56.1, R58.1, R59.2, R60.1, R62.2, R64.2, R66.2, R70.1, R71.1, R72.1, R76.1, R78.1, R79.2, R80.1, R82.2, R84.2, R86.2, R88.2, R90.2, TP3.1 (1_1), TP7.1 (1_1), TP11.1 (1_1), TP15.1 (1_1), U1.12 (VSSA), U1.18 (VSS), U1.63 (VSS), U2.8 (FSYNC), U2.9 (RESV), U2.10 (RESV), U2.11 (RESV), U2.12 (RESV), U2.13 (GND), U2.15 (RESV), U3.16 (VSS), U3.29 (VSS), U4.6 (COM), U4.25 (EXP), U5.16 (VSS), U5.29 (VSS), U6.6 (COM), U6.25 (EXP), U7.16 (VSS), U7.29 (VSS), U8.6 (COM), U8.25 (EXP), U9.16 (VSS), U9.29 (VSS), U10.6 (COM), U10.25 (EXP), U11.6 (GND), U11.9 (GNDPAD), U12.1 (GND), U13.2 (GND), U13.3 (GND), U13.6 (GND), U13.7 (GND), U14.4 (DGND), U14.20 (AGND), U14.23 (PGND), U15.1 (GND), U15.7 (GND)
HI11: U3.20 (PA10), U4.22 (HIN1)
HI12: U5.20 (PA10), U6.22 (HIN1)
HI13: U7.20 (PA10), U8.22 (HIN1)
HI14: U9.20 (PA10), U10.22 (HIN1)
HI21: U3.19 (PA9), U4.23 (HIN2)
HI22: U5.19 (PA9), U6.23 (HIN2)
HI23: U7.19 (PA9), U8.23 (HIN2)
HI24: U9.19 (PA9), U10.23 (HIN2)
HI31: U3.18 (PA8), U4.24 (HIN3)
HI32: U5.18 (PA8), U6.24 (HIN3)
HI33: U7.18 (PA8), U8.24 (HIN3)
HI34: U9.18 (PA8), U10.24 (HIN3)
INT: U1.14 (PA0), U2.6 (INT)
LI11: U3.15 (PB1), U4.1 (LIN1)
LI12: U5.15 (PB1), U6.1 (LIN1)
LI13: U7.15 (PB1), U8.1 (LIN1)
LI14: U9.15 (PB1), U10.1 (LIN1)
LI21: U3.14 (PB0), U4.2 (LIN2)
LI22: U5.14 (PB0), U6.2 (LIN2)
LI23: U7.14 (PB0), U8.2 (LIN2)
LI24: U9.14 (PB0), U10.2 (LIN2)
LI31: U3.13 (PA7), U4.3 (LIN3)
LI32: U5.13 (PA7), U6.3 (LIN3)
LI33: U7.13 (PA7), U8.3 (LIN3)
LI34: U9.13 (PA7), U10.3 (LIN3)
MISO B: U1.59 (PB7), U15.5 (SDO)
MISO IMU: U1.22 (PA6), U2.4 (SAO/SD0)
MISO SOD: U1.35 (PB14), U14.11 (SDOUT)
MOSI B: U1.58 (PB6), U15.3 (SDI)
MOSI IMU: U1.23 (PA7), U2.3 (SDA/SDI)
MOSI OSD: U1.36 (PB15), U14.9 (SDIN)
NRST: C5.1, R1.2, SW1.1 (A), U1.7 (NRST)
unnamed: C1.1, X1.2
unnamed: C2.1, X1.4
unnamed: C14.1, L1.2
unnamed: C70.2, C71.2, R91.2
unnamed: D1.1 (K), R4.2
unnamed: D2.1 (K), R5.2
unnamed: C24.1, D3.1 (K), U4.14 (VB3)
unnamed: C25.1, D4.1 (K), U4.17 (VB2)
unnamed: C26.1, D5.1 (K), U4.20 (VB1)
unnamed: C36.1, D6.1 (K), U6.20 (VB1)
unnamed: C37.1, D7.1 (K), U6.14 (VB3)
unnamed: C38.1, D8.1 (K), U6.17 (VB2)
unnamed: C45.1, D9.1 (K), U8.20 (VB1)
unnamed: C46.1, D10.1 (K), U8.14 (VB3)
unnamed: C47.1, D11.1 (K), U8.17 (VB2)
unnamed: C54.1, D12.1 (K), U10.20 (VB1)
unnamed: C55.1, D13.1 (K), U10.14 (VB3)
unnamed: C56.1, D14.1 (K), U10.17 (VB2)
unnamed: C58.2, D15.1 (K), L2.1, U11.8 (PH)
unnamed: C69.2, J8.1, R90.1
unnamed: J9.1, R91.1
unnamed: Q1.3 (S), R18.1
unnamed: Q2.1 (G), R20.1
unnamed: Q3.3 (S), R22.1
unnamed: Q4.1 (G), R23.1
unnamed: Q5.3 (S), R26.1
unnamed: Q6.1 (G), R25.1
unnamed: Q7.3 (S), R42.1
unnamed: Q8.1 (G), R41.1
unnamed: Q9.3 (S), R44.1
unnamed: Q10.1 (G), R43.1
unnamed: Q11.3 (S), R46.1
unnamed: Q12.1 (G), R45.1
unnamed: Q13.3 (S), R62.1
unnamed: Q14.1 (G), R61.1
unnamed: Q15.3 (S), R64.1
unnamed: Q16.1 (G), R63.1
unnamed: Q17.3 (S), R66.1
unnamed: Q18.1 (G), R65.1
unnamed: Q19.3 (S), R82.1
unnamed: Q20.1 (G), R81.1
unnamed: Q21.3 (S), R84.1
unnamed: Q22.1 (G), R83.1
unnamed: Q23.3 (S), R86.1
unnamed: Q24.1 (G), R85.1
unnamed: C5.2, SW1.2 (B)
unnamed: +10ppm1.1, C4.1, U1.3 (PC14)
unnamed: +10ppm1.2, C3.1, U1.4 (PC15)
unnamed: C1.2, U1.5 (PH0), X1.1
unnamed: C2.2, U1.6 (PH1), X1.3
unnamed: C8.1, U1.31 (VCAP_1)
unnamed: C7.1, U1.47 (VCAP_2)
unnamed: C17.1, U2.14 (REGOUT)
unnamed: R7.2, U3.1 (BOOT0)
unnamed: R8.2, U3.4 (NRST)
unnamed: R10.1, R14.2, R17.2, U3.6 (PA0)
unnamed: R9.2, R10.2, R11.2, U3.7 (PA1)
unnamed: R11.1, R12.2, R16.2, U3.10 (PA4)
unnamed: R9.1, R13.2, R15.2, U3.11 (PA5)
unnamed: R36.2, U5.1 (BOOT0)
unnamed: R37.2, U5.4 (NRST)
unnamed: R29.2, R30.2, R35.1, U5.6 (PA0)
unnamed: R33.2, R34.2, R35.2, U5.7 (PA1)
unnamed: R28.2, R32.2, R34.1, U5.10 (PA4)
unnamed: R27.2, R31.2, R33.1, U5.11 (PA5)
unnamed: R56.2, U7.1 (BOOT0)
unnamed: R57.2, U7.4 (NRST)
unnamed: R49.2, R50.2, R55.1, U7.6 (PA0)
unnamed: R53.2, R54.2, R55.2, U7.7 (PA1)
unnamed: R48.2, R52.2, R54.1, U7.10 (PA4)
unnamed: R47.2, R51.2, R53.1, U7.11 (PA5)
unnamed: R76.2, U9.1 (BOOT0)
unnamed: R77.2, U9.4 (NRST)
unnamed: R69.2, R70.2, R75.1, U9.6 (PA0)
unnamed: R73.2, R74.2, R75.2, U9.7 (PA1)
unnamed: R68.2, R72.2, R74.1, U9.10 (PA4)
unnamed: R67.2, R71.2, R73.1, U9.11 (PA5)
unnamed: C58.1, U11.1 (BOOT)
unnamed: R89.2, U11.5 (EN)
unnamed: R87.2, R88.1, U11.4 (VSENSE)
PA1: U1.15 (PA1)
PA2: U1.16 (PA2)
PA3: U1.17 (PA3)
PA12: U1.45 (PA12)
PA15: U1.50 (PA15)
PB0: U1.26 (PB0)
PB1: U1.27 (PB1)
PB2: R3.1, R4.1, U1.28 (PB2)
PB3: U1.55 (PB3)
PB4: U1.56 (PB4)
PB9: U1.62 (PB9)
PB10: U1.29 (PB10)
PB11: U1.30 (PB11)
PC0: U1.8 (PC0)
PC1: U1.9 (PC1)
PC2: U1.10 (PC2)
PC3: U1.11 (PC3)
PC4: U1.24 (PC4)
PC5: U1.25 (PC5)
PC6: U1.37 (PC6)
PC7: U1.38 (PC7)
PC8: U1.39 (PC8)
PC10: U1.51 (PC10)
PC11: U1.52 (PC11)
PC12: U1.53 (PC12)
PC13: U1.2 (PC13)
PD2: U1.54 (PD2)
PWM1: U1.41 (PA8), U3.8 (PA2)
PWM2: U1.42 (PA9), U5.8 (PA2)
PWM3: U1.43 (PA10), U7.8 (PA2)
PWM4: U1.44 (PA11), U9.8 (PA2)
SAG: C71.1, U14.25 (SAG)
SCK B: U1.57 (PB5), U15.4 (SCK)
SCK IMU: U1.21 (PA5), U2.2 (SCL/SPC)
SCK SOD: U1.34 (PB13), U14.10 (SCLK)
SWCLK: J1.4, U1.49 (PA14)
SWCLK1: TP4.1 (1_1), U3.22 (PA14)
SWCLK2: TP8.1 (1_1), U5.22 (PA14)
SWCLK3: TP12.1 (1_1), U7.22 (PA14)
SWCLK4: TP16.1 (1_1), U9.22 (PA14)
SWDIO: J1.2, U1.46 (PA13)
SWDIO1: TP5.1 (1_1), U3.21 (PA13)
SWDIO2: TP9.1 (1_1), U5.21 (PA13)
SWDIO3: TP13.1 (1_1), U7.21 (PA13)
SWDIO4: TP17.1 (1_1), U9.21 (PA13)
VDD: C18.1, C19.1, C20.1, U2.1 (VDDIO), U2.16 (VDD)
VDD33: C6.1, C9.1, C10.1, C11.1, C12.1, C13.1, C21.2, C22.1, C32.2, C34.1, C41.2, C43.1, C50.2, C52.1, C60.1, C61.1, C72.1, C73.1, J1.1, L1.1, R1.1, R5.1, R8.1, R37.1, R57.1, R77.1, SW2.2 (B), TP2.1 (1_1), TP6.1 (1_1), TP10.1 (1_1), TP14.1 (1_1), U1.1 (VBAT), U1.13 (VDDA), U1.19 (VDD), U1.32 (VDD), U1.48 (VDD), U1.64 (VDD), U3.5 (VDDA), U3.17 (VDD), U5.5 (VDDA), U5.17 (VDD), U7.5 (VDDA), U7.17 (VDD), U9.5 (VDDA), U9.17 (VDD), U12.2 (VO), U15.6 (VDDIO), U15.8 (VDD)
VIN: C27.1, C28.1, C29.1, C30.1, C31.1, C33.1, C39.1, C40.1, C42.1, C48.1, C49.1, C51.1, C57.1, C64.1, C69.1, J7.1, Q2.2 (D), Q4.2 (D), Q6.2 (D), Q8.2 (D), Q10.2 (D), Q12.2 (D), Q14.2 (D), Q16.2 (D), Q18.2 (D), Q20.2 (D), Q22.2 (D), Q24.2 (D), R89.1, U11.7 (VIN), U13.8 (IN), U14.22 (VIN)
VOUT: C59.1, C70.1, L2.2, R87.1, U14.26 (VOUT)
XTAL1: U14.5 (CLKIN), Y1.1
XTAL2: U14.6 (XFB), Y1.2

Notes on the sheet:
Indicator light
Reset circuit
BMP280 Barometer
ESC1
Battery connection
ESC4
OSD - AT7456E
BOOT Settings
ESC3
Power - Buck (5V) + LDO (3.3V)
SW debug download interface
ESC2
IMU sensonr
MIAN MCU

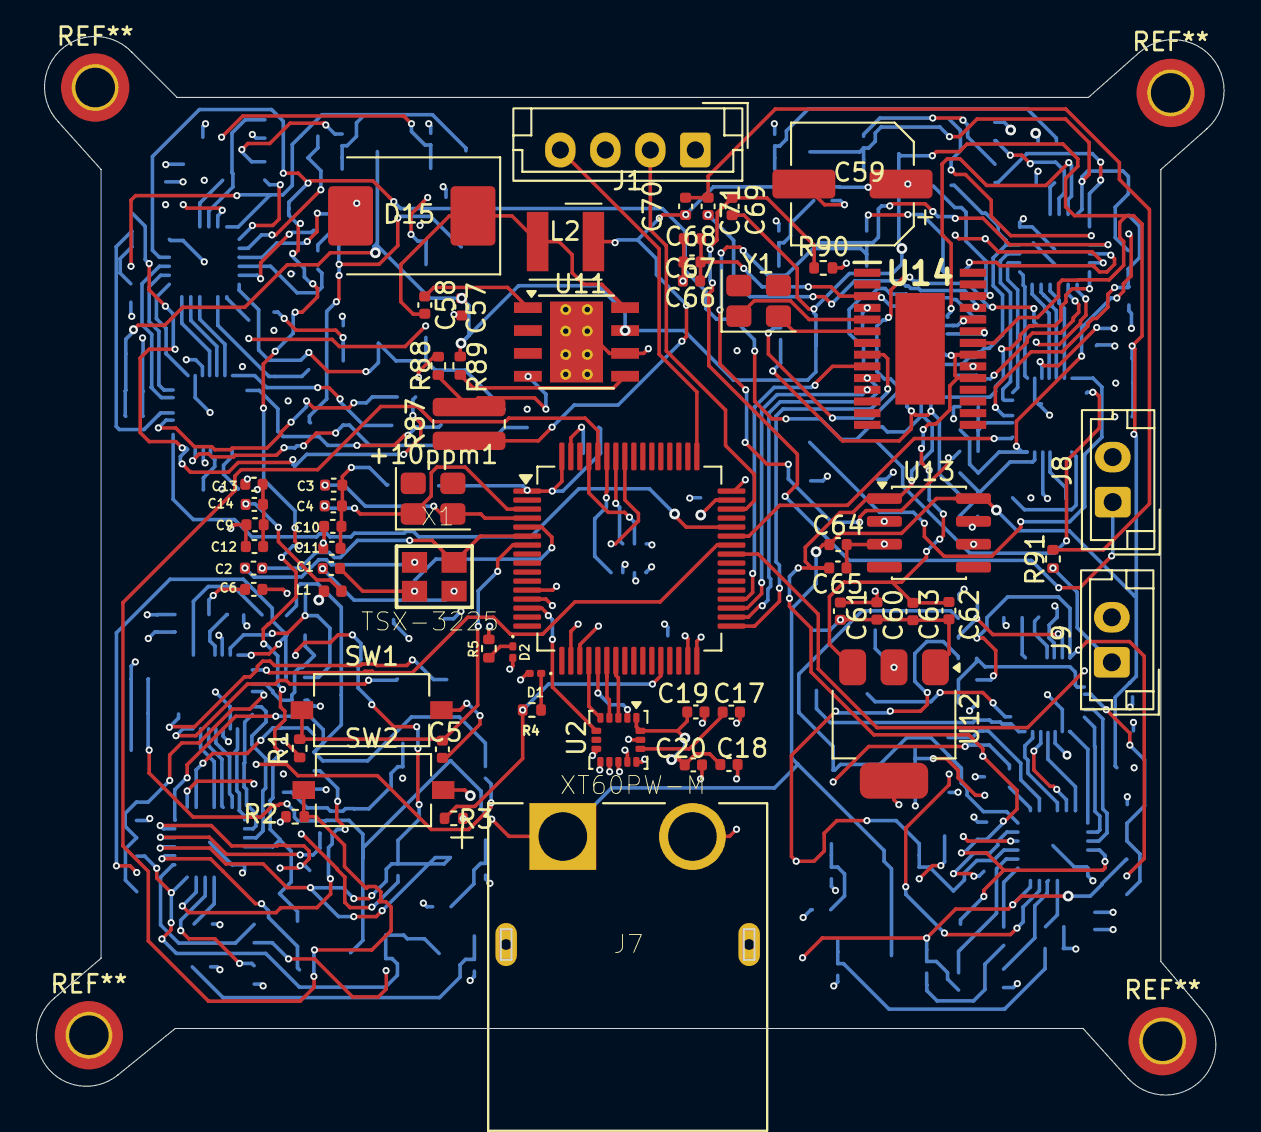
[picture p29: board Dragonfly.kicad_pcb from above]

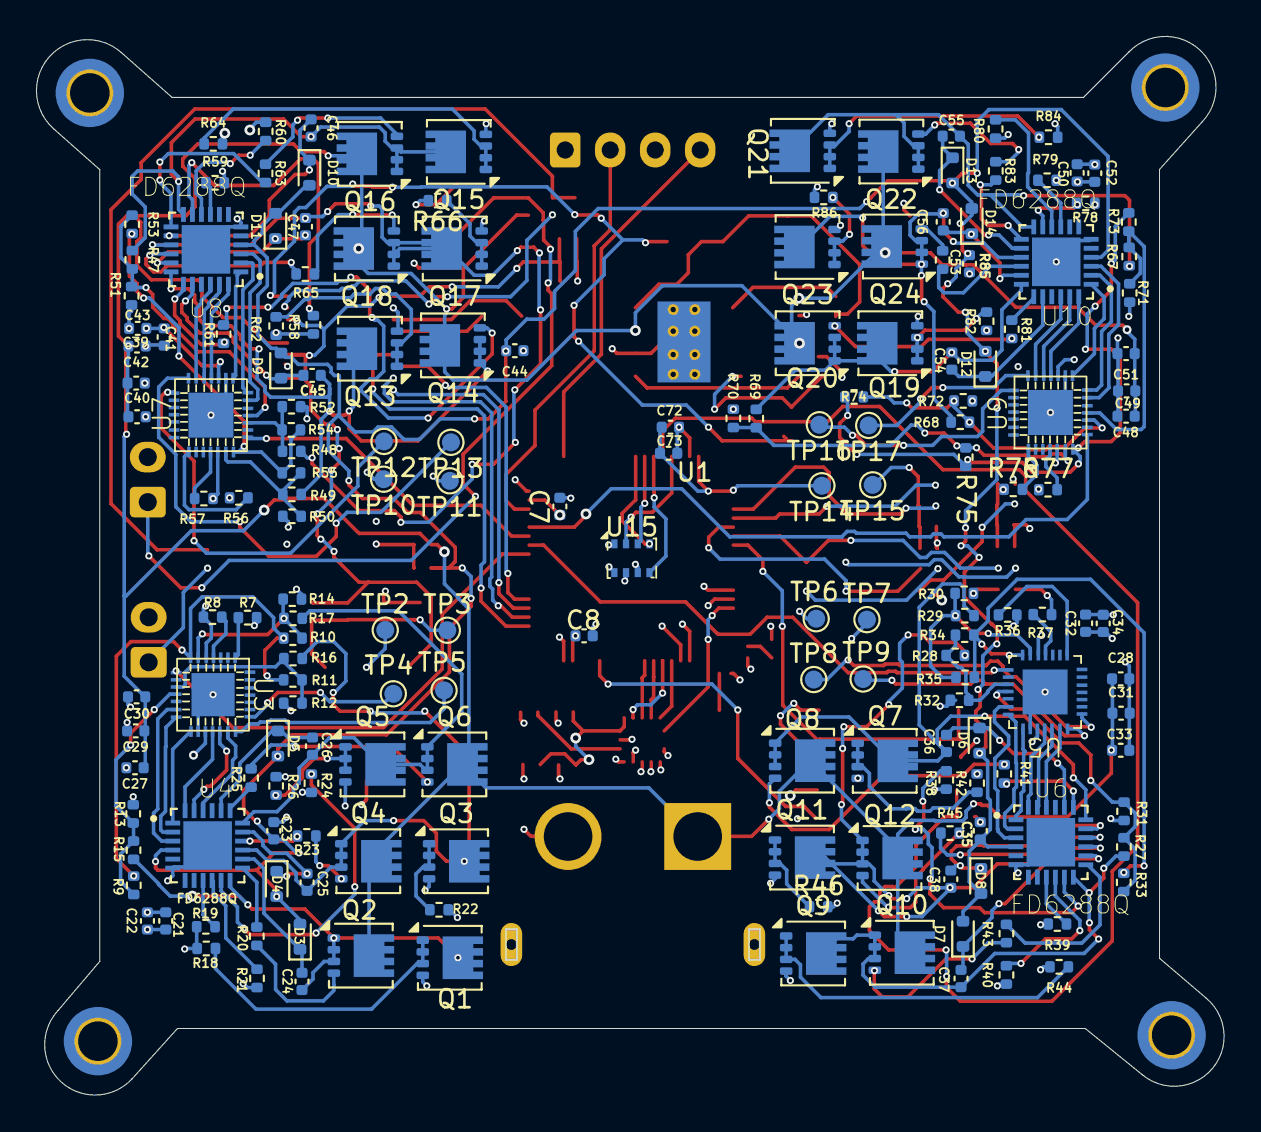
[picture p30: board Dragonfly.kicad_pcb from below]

Board: 4 copper layers, 66.0 x 58.8 mm, 242 parts (181 on the bottom side), 180 nets.

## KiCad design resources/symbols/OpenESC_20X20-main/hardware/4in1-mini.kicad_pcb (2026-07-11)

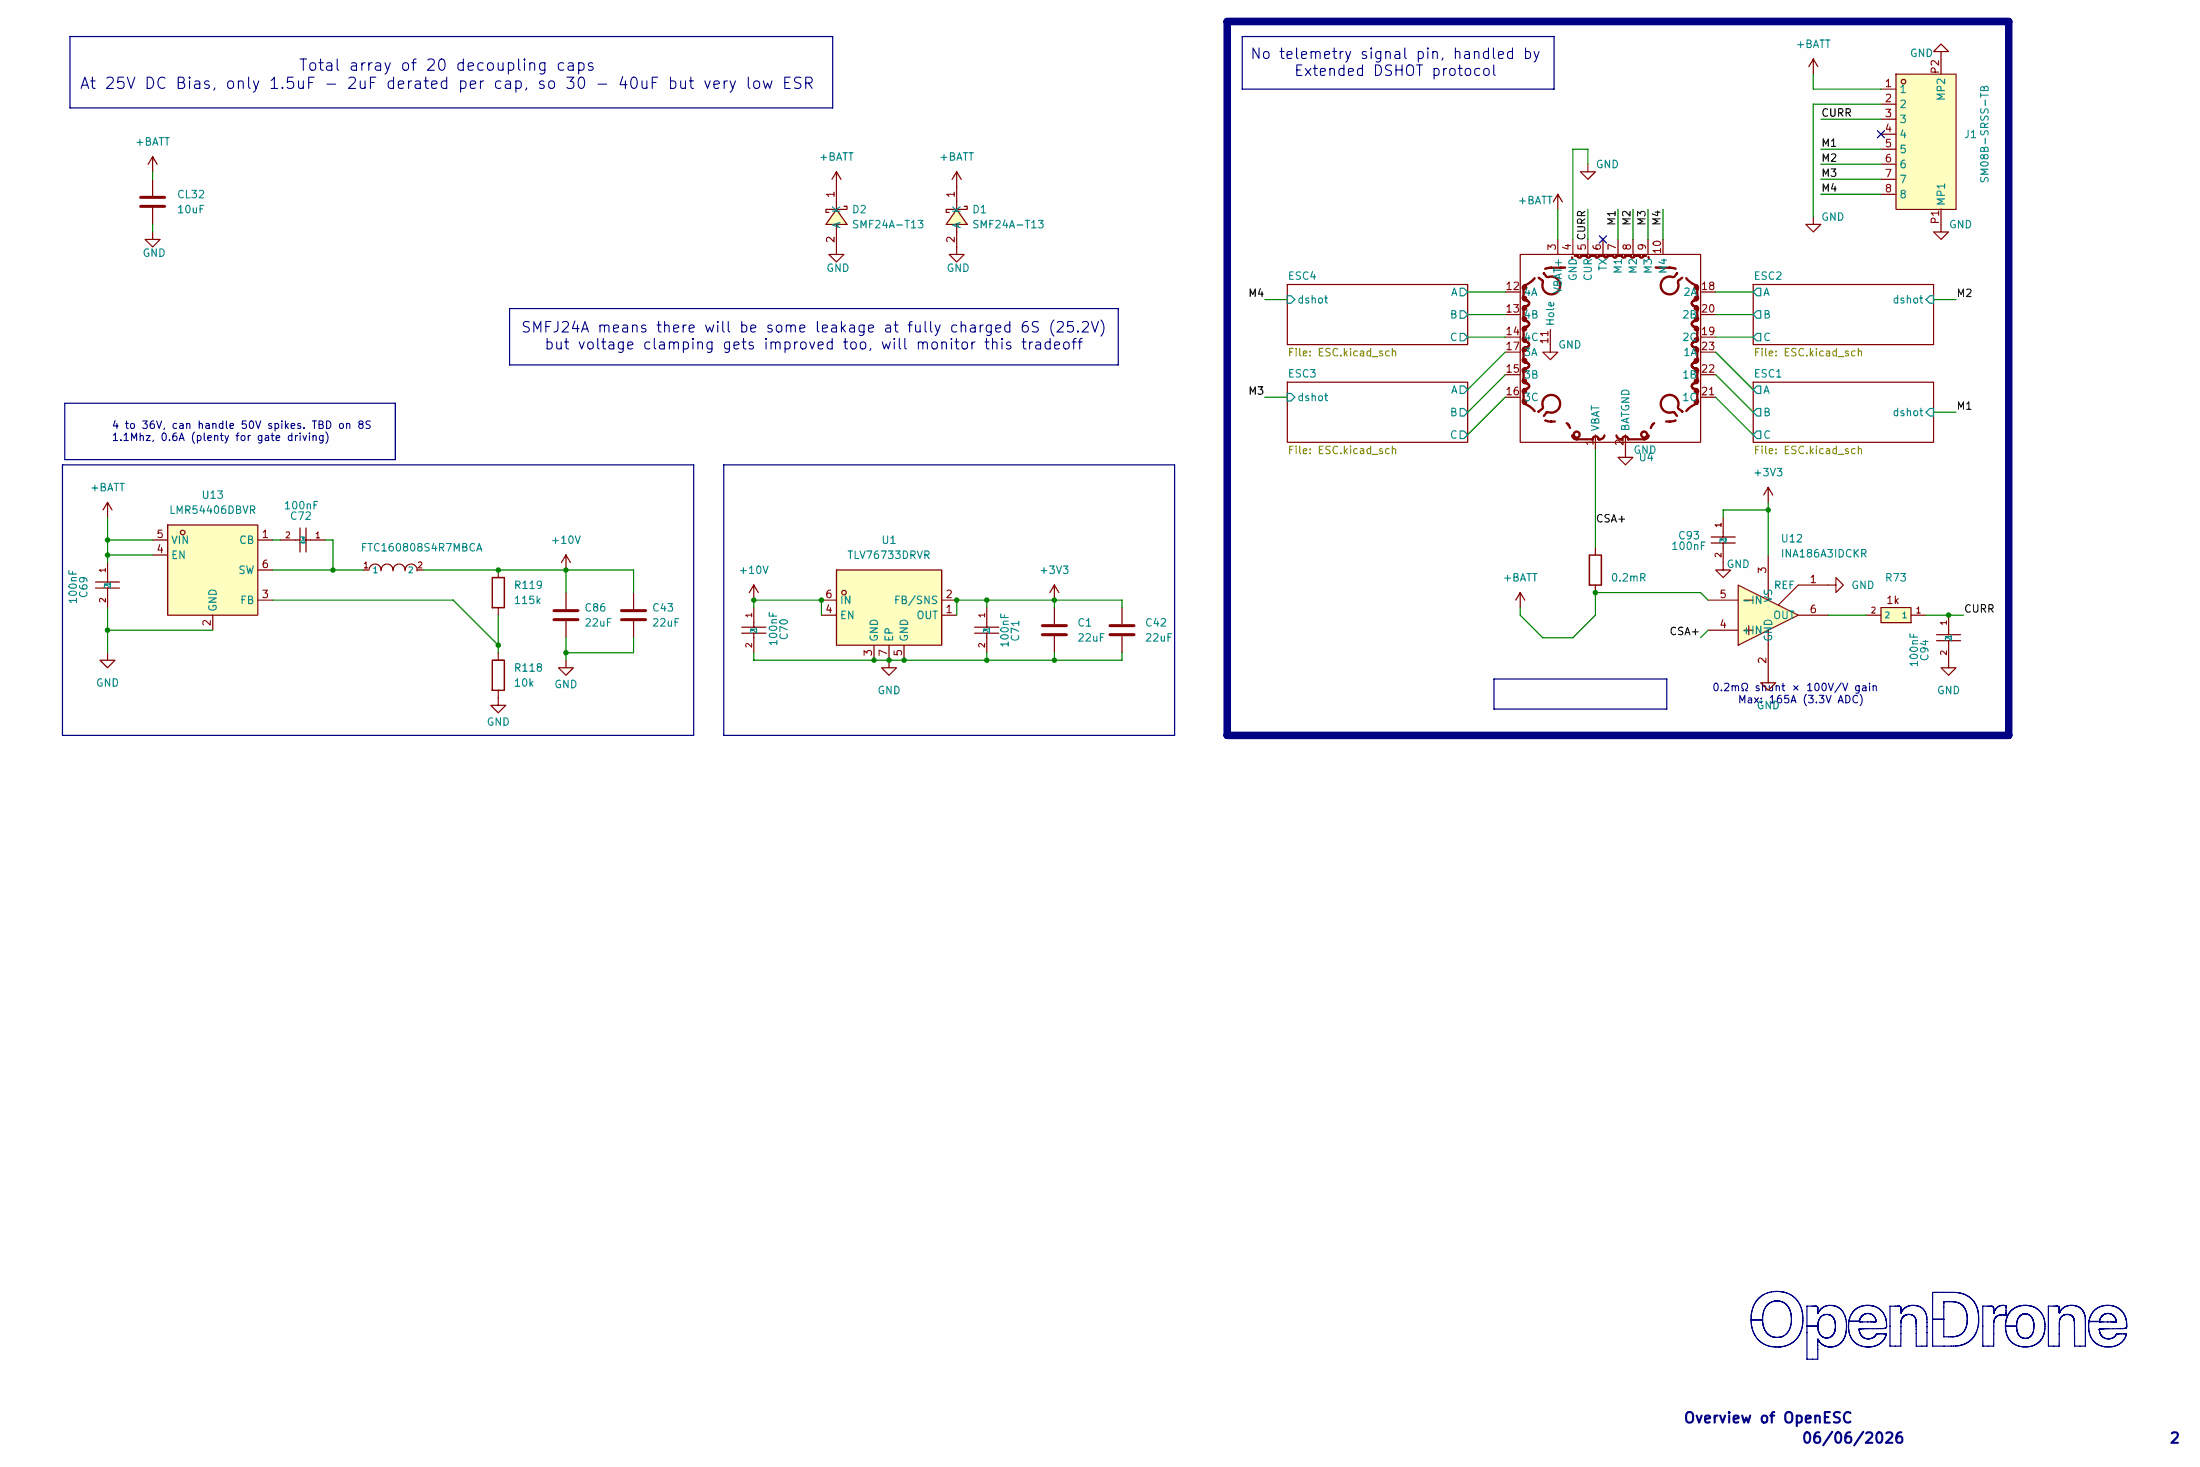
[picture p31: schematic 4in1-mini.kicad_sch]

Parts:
C1, C42: 22uF; C_0402_1005Metric; MPN CL05A226MQ5QUNC; LCSC C105226
C43, C86: 22uF; C_0603_1608Metric; MPN CL10A226MO7JZNC; LCSC C2762594
C69, C70, C71, C72, C93, C94: 100nF; C_0201_0603Metric; MPN GRM033R6YA104KE14D; LCSC C181043
CL32: 10uF; C_1206_3216Metric; MPN CL31B106KBHNNNE; LCSC C89632
D1, D2: SMF24A-T13; SOD-123FL_L2.7-W1.8-LS3.7-RD; MPN SMF24A-T13; LCSC Part C1977154
J1: SM08B-SRSS-TB; JST_SM08B-SRSS-TB; MPN SM08B-SRSS-TB(LF)(SN); LCSC C160407
R73: 1k; R_0201_0603Metric; MPN 0201WMF1001TEE; LCSC C270365
R118: 10k; R_0201_0603Metric; MPN RC0201FR-0710KL; LCSC C106225
R119: 115k; R_0201_0603Metric; MPN RTT011153FTH; LCSC C166378
Rsense1: 0.2mR; R_2512_6332Metric; MPN ASR-S-3-0.2F; LCSC C695806
U1: TLV76733DRVR; WSON-6_L2.0-W2.0-P0.65-TL-EP; MPN TLV76733DRVR; LCSC C2848334
U4: 4in1ESC
U5: FTC160808S4R7MBCA; IND-SMD_L1.6-W0.8_FTC160865SR47MBCA; MPN FTC160808S4R7MBCA; LCSC C46594347
U12: INA186A3IDCKR; SOT-363_SC-70-6; MPN INA186A3IDCKR; LCSC C2058245
U13: LMR54406DBVR; SOT-23-6_L2.9-W1.6-P0.95-LS2.8-BR; MPN LMR54406DBVR; LCSC Part C5219316

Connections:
+3V3: C1.2, C42.2, C71.1, C93.1, U1.1 (OUT), U1.2 (FB/SNS), U12.3 (VS); also elsewhere on the board
+10V: C43.1, C70.1, C86.1, R119.1, U1.4 (EN), U1.6 (IN), U5.2; also elsewhere on the board
+BATT: C69.1, CL32.1, D1.1 (K), D2.1 (K), J1.1, Rsense1.2, U4.3 (VBAT+), U12.5 (-IN), U13.4 (EN), U13.5 (VIN); also elsewhere on the board
/CSA+: Rsense1.1, U4.1 (VBAT), U12.4 (+IN)
/CURR: C94.1, J1.3, R73.1, U4.5 (CUR)
/ESC1/MotorA: U4.23 (1A); also elsewhere on the board
/ESC1/MotorB: U4.22 (1B); also elsewhere on the board
/ESC1/MotorC: U4.21 (1C); also elsewhere on the board
/ESC2/MotorA: U4.18 (2A); also elsewhere on the board
/ESC2/MotorB: U4.20 (2B); also elsewhere on the board
/ESC2/MotorC: U4.19 (2C); also elsewhere on the board
/ESC3/MotorA: U4.17 (3A); also elsewhere on the board
/ESC3/MotorB: U4.15 (3B); also elsewhere on the board
/ESC3/MotorC: U4.16 (3C); also elsewhere on the board
/ESC4/MotorA: U4.12 (4A); also elsewhere on the board
/ESC4/MotorB: U4.13 (4B); also elsewhere on the board
/ESC4/MotorC: U4.14 (4C); also elsewhere on the board
/M1: J1.5, U4.7 (M1); also elsewhere on the board
/M2: J1.6, U4.8 (M2); also elsewhere on the board
/M3: J1.7, U4.9 (M3); also elsewhere on the board
/M4: J1.8, U4.10 (M4); also elsewhere on the board
GND: C1.1, C42.1, C43.2, C69.2, C70.2, C71.2, C86.2, C93.2, C94.2, CL32.2, D1.2 (A), D2.2 (A), J1.2, J1.P1 (MP1), J1.P2 (MP2), R118.2, U1.3 (GND), U1.5 (GND), U1.7 (EP), U4.2 (BATGND), U4.4 (GND), U4.11 (Hole), U12.1 (REF), U12.2 (GND), U13.2 (GND); also elsewhere on the board
unnamed: R73.2, U12.6 (OUT)
unnamed: C72.2, U13.1 (CB)
unnamed: R118.1, R119.2, U13.3 (FB)
unnamed: C72.1, U5.1, U13.6 (SW)

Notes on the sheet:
06/06/2026
No telemetry signal pin, handled by Extended DSHOT protocol
4 to 36V, can handle 50V spikes. TBD on 8S 1.1Mhz, 0.6A (plenty for gate driving)
SMFJ24A means there will be some leakage at fully charged 6S (25.2V) but voltage clamping gets improved too, will monitor this tradeoff
Overview of OpenESC
Total array of 20 decoupling caps At 25V DC Bias, only 1.5uF - 2uF derated per cap, so 30 - 40uF but very low ESR
0.2mΩ shunt × 100V/V gain Max: 165A (3.3V ADC)

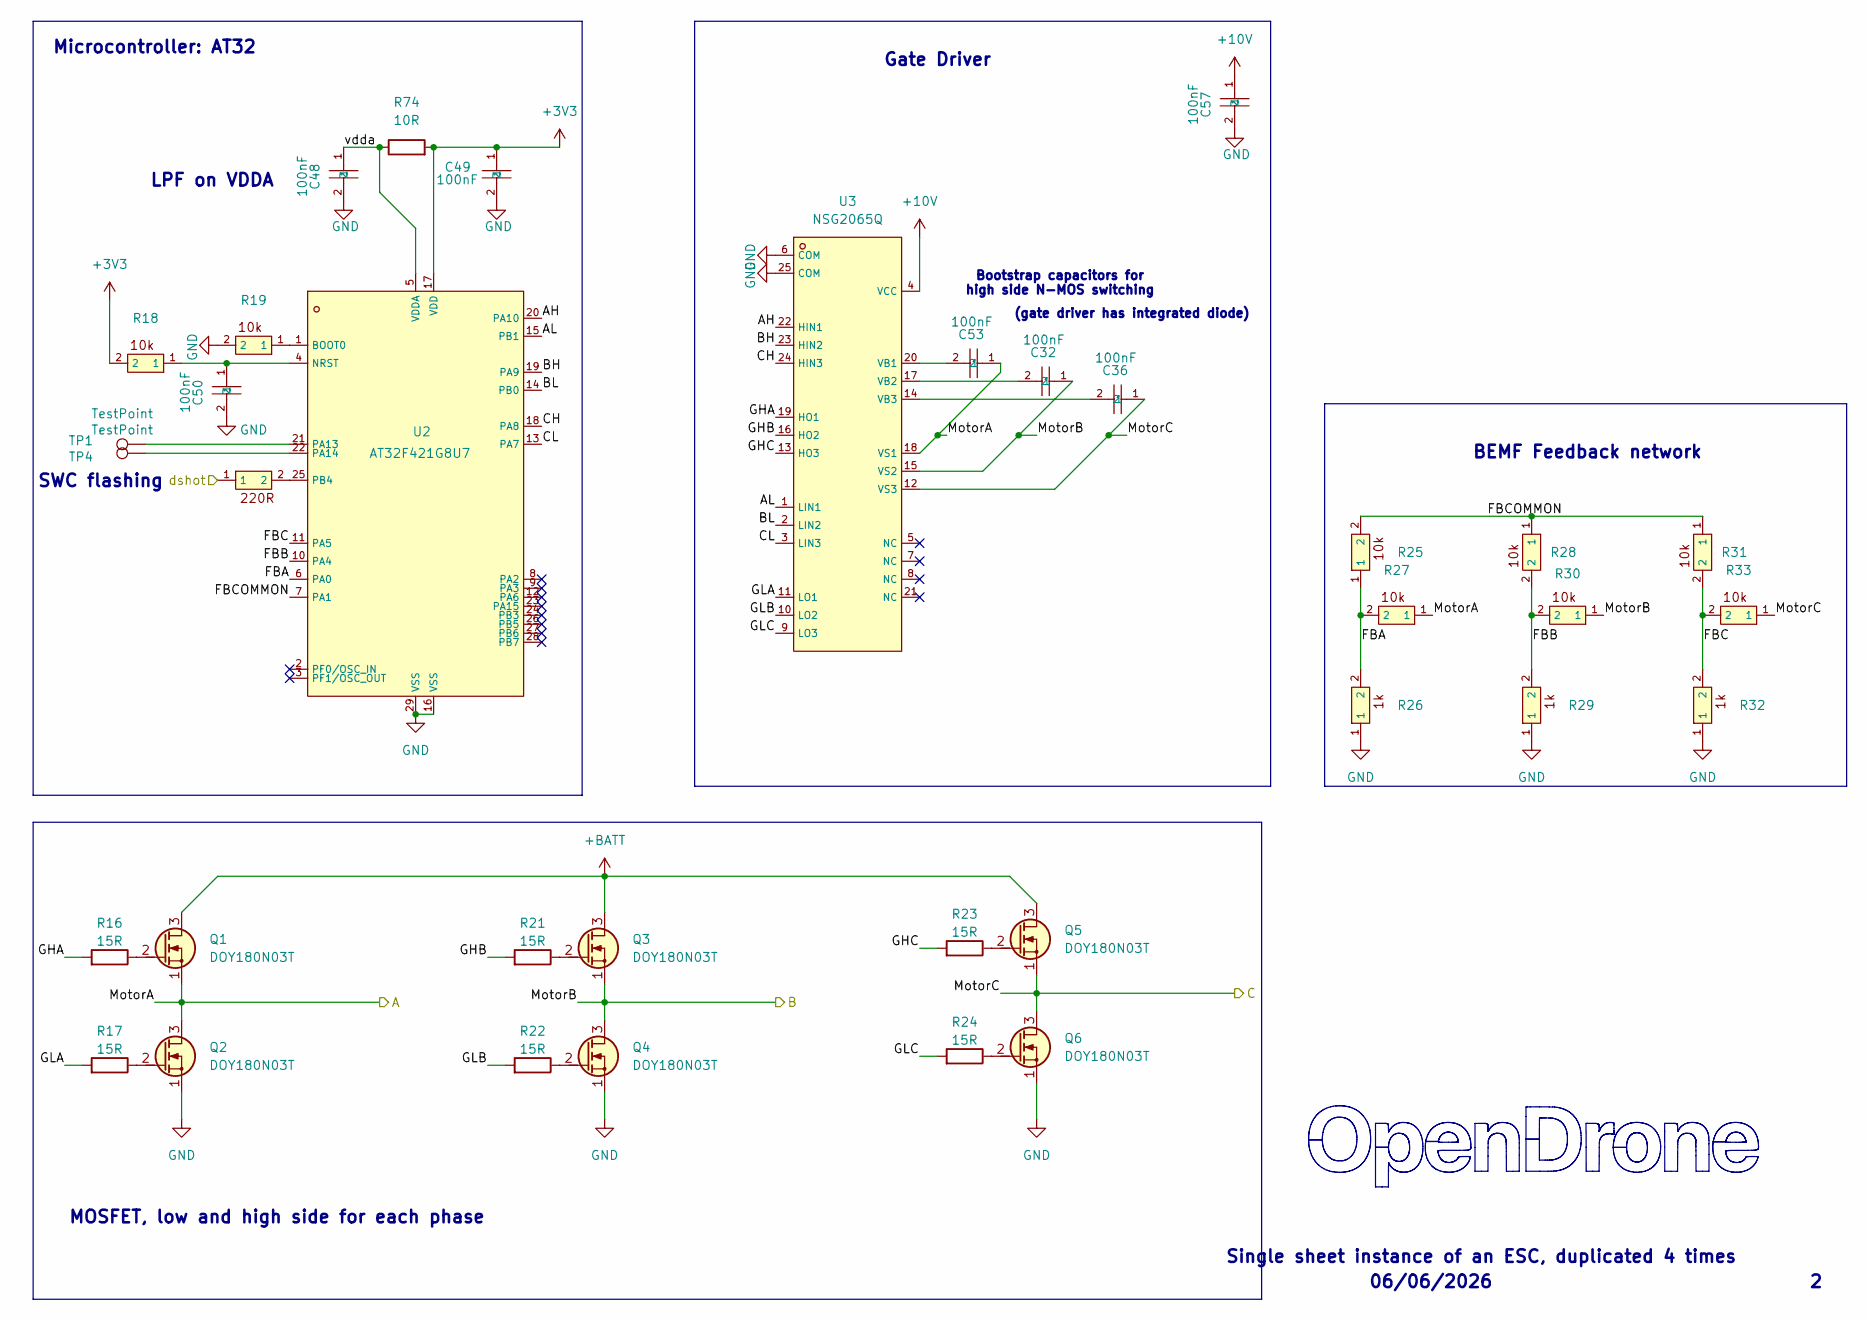
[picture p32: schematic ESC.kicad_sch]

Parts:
C32, C36, C53: 100nF; C_0402_WIDE; MPN CL05B104KB54PNC; LCSC C307331
C48, C49, C50, C57: 100nF; C_0201_0603Metric; MPN GRM033R6YA104KE14D; LCSC C181043
Q1, Q2, Q3, Q4, Q5, Q6: DOY180N03T; Diodes_PowerDI3333-8; MPN DOY180N03T; LCSC C49441966
R16, R17, R21, R22, R23, R24: 15R; R_0201_0603Metric; MPN 0201WMF150JTEE; LCSC C473542
R18, R19, R25, R27, R28, R30, R31, R33: 10k; R_0201_0603Metric; MPN RC0201FR-0710KL; LCSC C106225
R20: 220R; R_0201_0603Metric; MPN AC0201FR-07220RL; LCSC C226468
R26, R29, R32: 1k; R_0201_0603Metric; MPN 0201WMF1001TEE; LCSC C270365
R74: 10R; R_0201_0603Metric; MPN RC0201FR-0710RL; LCSC C106226
TP1, TP4: TestPoint; TestPoint_Pad_D1.0mm
U2: AT32F421G8U7; QFN-28_L4.0-W4.0-P0.40-TL-EP2.4; MPN AT32F421G8U7; LCSC C2765098
U3: NSG2065Q; QFN-24_L4.0-W4.0-P0.50-TL-EP2.8; MPN NSG2065Q; LCSC C41414478

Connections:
+3V3: C49.1, R18.2, R74.2, U2.17 (VDD); also elsewhere on the board
+10V: C57.1, U3.4 (VCC); also elsewhere on the board
+BATT: Q1.3 (D), Q3.3 (D), Q5.3 (D); also elsewhere on the board
/ESC1/AH: U2.20 (PA10), U3.22 (HIN1)
/ESC1/AL: U2.15 (PB1), U3.1 (LIN1)
/ESC1/BH: U2.19 (PA9), U3.23 (HIN2)
/ESC1/BL: U2.14 (PB0), U3.2 (LIN2)
/ESC1/CH: U2.18 (PA8), U3.24 (HIN3)
/ESC1/CL: U2.13 (PA7), U3.3 (LIN3)
/ESC1/FBA: R25.1, R26.2, R27.2, U2.6 (PA0)
/ESC1/FBB: R28.2, R29.2, R30.2, U2.10 (PA4)
/ESC1/FBC: R31.2, R32.2, R33.2, U2.11 (PA5)
/ESC1/FBCOMMON: R25.2, R28.1, R31.1, U2.7 (PA1)
/ESC1/GHA: R16.1, U3.19 (HO1)
/ESC1/GHB: R21.1, U3.16 (HO2)
/ESC1/GHC: R23.1, U3.13 (HO3)
/ESC1/GLA: R17.1, U3.11 (LO1)
/ESC1/GLB: R22.1, U3.10 (LO2)
/ESC1/GLC: R24.1, U3.9 (LO3)
/ESC1/MotorA: C53.1, Q1.1 (S), Q2.3 (D), R27.1, U3.18 (VS1); also elsewhere on the board
/ESC1/MotorB: C32.1, Q3.1 (S), Q4.3 (D), R30.1, U3.15 (VS2); also elsewhere on the board
/ESC1/MotorC: C36.1, Q5.1 (S), Q6.3 (D), R33.1, U3.12 (VS3); also elsewhere on the board
/ESC1/vdda: C48.1, R74.1, U2.5 (VDDA)
/M1: R20.1; also elsewhere on the board
GND: C48.2, C49.2, C50.2, C57.2, Q2.1 (S), Q4.1 (S), Q6.1 (S), R19.2, R26.1, R29.1, R32.1, U2.16 (VSS), U2.29 (VSS), U3.6 (COM), U3.25 (COM); also elsewhere on the board
unnamed: Q1.2 (G), R16.2
unnamed: Q2.2 (G), R17.2
unnamed: Q3.2 (G), R21.2
unnamed: Q4.2 (G), R22.2
unnamed: Q5.2 (G), R23.2
unnamed: Q6.2 (G), R24.2
unnamed: R19.1, U2.1 (BOOT0)
unnamed: C50.1, R18.1, U2.4 (NRST)
unnamed: TP1.1 (1_1), U2.21 (PA13)
unnamed: TP4.1 (1_1), U2.22 (PA14)
unnamed: R20.2, U2.25 (PB4)
unnamed: C53.2, U3.20 (VB1)
unnamed: C32.2, U3.17 (VB2)
unnamed: C36.2, U3.14 (VB3)

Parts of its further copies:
C33, C34, C35, C37, C38, C39, C59, C73, C83: 100nF; C_0402_WIDE; MPN CL05B104KB54PNC; LCSC C307331
C44, C45, C46, C63, C64, C65, C66, C77, C78, C79, C80, C88: 100nF; C_0201_0603Metric; MPN GRM033R6YA104KE14D; LCSC C181043
Q7, Q8, Q9, Q10, Q11, Q12, Q13, Q14, Q15, Q16, Q17, Q18, Q19, Q20, Q21, Q22, Q23, Q24: DOY180N03T; Diodes_PowerDI3333-8; MPN DOY180N03T; LCSC C49441966
R1, R2, R6, R7, R8, R9, R37, R38, R42, R43, R44, R45, R55, R56, R60, R61, R62, R63: 15R; R_0201_0603Metric; MPN 0201WMF150JTEE; LCSC C473542
R3, R4, R10, R12, R13, R15, R34, R36, R39, R40, R46, R48, R49, R51, R52, R54, R57, R58, R64, R66, R67, R69, R70, R72: 10k; R_0201_0603Metric; MPN RC0201FR-0710KL; LCSC C106225
R5, R41, R59: 220R; R_0201_0603Metric; MPN AC0201FR-07220RL; LCSC C226468
R11, R14, R35, R47, R50, R53, R65, R68, R71: 1k; R_0201_0603Metric; MPN 0201WMF1001TEE; LCSC C270365
R75, R76, R77: 10R; R_0201_0603Metric; MPN RC0201FR-0710RL; LCSC C106226
TP2, TP3, TP5, TP6, TP7, TP8: TestPoint; TestPoint_Pad_D1.0mm
U6, U8, U10: AT32F421G8U7; QFN-28_L4.0-W4.0-P0.40-TL-EP2.4; MPN AT32F421G8U7; LCSC C2765098
U7, U9, U11: NSG2065Q; QFN-24_L4.0-W4.0-P0.50-TL-EP2.8; MPN NSG2065Q; LCSC C41414478

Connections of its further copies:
+3V3: C45.1, C65.1, C79.1, R3.2, R39.2, R57.2, R75.2, R76.2, R77.2, U6.17 (VDD), U8.17 (VDD), U10.17 (VDD); also elsewhere on the board
+10V: C63.1, C77.1, C88.1, U7.4 (VCC), U9.4 (VCC), U11.4 (VCC); also elsewhere on the board
+BATT: Q7.3 (D), Q9.3 (D), Q11.3 (D), Q13.3 (D), Q15.3 (D), Q17.3 (D), Q19.3 (D), Q21.3 (D), Q23.3 (D); also elsewhere on the board
/ESC2/AH: U6.20 (PA10), U7.22 (HIN1)
/ESC2/AL: U6.15 (PB1), U7.1 (LIN1)
/ESC2/BH: U6.19 (PA9), U7.23 (HIN2)
/ESC2/BL: U6.14 (PB0), U7.2 (LIN2)
/ESC2/CH: U6.18 (PA8), U7.24 (HIN3)
/ESC2/CL: U6.13 (PA7), U7.3 (LIN3)
/ESC2/FBA: R10.1, R11.2, R12.2, U6.6 (PA0)
/ESC2/FBB: R13.2, R14.2, R15.2, U6.10 (PA4)
/ESC2/FBC: R34.2, R35.2, R36.2, U6.11 (PA5)
/ESC2/FBCOMMON: R10.2, R13.1, R34.1, U6.7 (PA1)
/ESC2/GHA: R1.1, U7.19 (HO1)
/ESC2/GHB: R6.1, U7.16 (HO2)
/ESC2/GHC: R8.1, U7.13 (HO3)
/ESC2/GLA: R2.1, U7.11 (LO1)
/ESC2/GLB: R7.1, U7.10 (LO2)
/ESC2/GLC: R9.1, U7.9 (LO3)
/ESC2/MotorA: C59.1, Q7.1 (S), Q8.3 (D), R12.1, U7.18 (VS1); also elsewhere on the board
/ESC2/MotorB: C33.1, Q9.1 (S), Q10.3 (D), R15.1, U7.15 (VS2); also elsewhere on the board
/ESC2/MotorC: C37.1, Q11.1 (S), Q12.3 (D), R36.1, U7.12 (VS3); also elsewhere on the board
/ESC2/vdda: C44.1, R75.1, U6.5 (VDDA)
/ESC3/AH: U8.20 (PA10), U9.22 (HIN1)
/ESC3/AL: U8.15 (PB1), U9.1 (LIN1)
/ESC3/BH: U8.19 (PA9), U9.23 (HIN2)
/ESC3/BL: U8.14 (PB0), U9.2 (LIN2)
/ESC3/CH: U8.18 (PA8), U9.24 (HIN3)
/ESC3/CL: U8.13 (PA7), U9.3 (LIN3)
/ESC3/FBA: R46.1, R47.2, R48.2, U8.6 (PA0)
/ESC3/FBB: R49.2, R50.2, R51.2, U8.10 (PA4)
/ESC3/FBC: R52.2, R53.2, R54.2, U8.11 (PA5)
/ESC3/FBCOMMON: R46.2, R49.1, R52.1, U8.7 (PA1)
/ESC3/GHA: R37.1, U9.19 (HO1)
/ESC3/GHB: R42.1, U9.16 (HO2)
/ESC3/GHC: R44.1, U9.13 (HO3)
/ESC3/GLA: R38.1, U9.11 (LO1)
/ESC3/GLB: R43.1, U9.10 (LO2)
/ESC3/GLC: R45.1, U9.9 (LO3)
/ESC3/MotorA: C73.1, Q13.1 (S), Q14.3 (D), R48.1, U9.18 (VS1); also elsewhere on the board
/ESC3/MotorB: C34.1, Q15.1 (S), Q16.3 (D), R51.1, U9.15 (VS2); also elsewhere on the board
/ESC3/MotorC: C38.1, Q17.1 (S), Q18.3 (D), R54.1, U9.12 (VS3); also elsewhere on the board
/ESC3/vdda: C64.1, R76.1, U8.5 (VDDA)
/ESC4/AH: U10.20 (PA10), U11.22 (HIN1)
/ESC4/AL: U10.15 (PB1), U11.1 (LIN1)
/ESC4/BH: U10.19 (PA9), U11.23 (HIN2)
/ESC4/BL: U10.14 (PB0), U11.2 (LIN2)
/ESC4/CH: U10.18 (PA8), U11.24 (HIN3)
/ESC4/CL: U10.13 (PA7), U11.3 (LIN3)
/ESC4/FBA: R64.1, R65.2, R66.2, U10.6 (PA0)
/ESC4/FBB: R67.2, R68.2, R69.2, U10.10 (PA4)
/ESC4/FBC: R70.2, R71.2, R72.2, U10.11 (PA5)
/ESC4/FBCOMMON: R64.2, R67.1, R70.1, U10.7 (PA1)
/ESC4/GHA: R55.1, U11.19 (HO1)
/ESC4/GHB: R60.1, U11.16 (HO2)
/ESC4/GHC: R62.1, U11.13 (HO3)
/ESC4/GLA: R56.1, U11.11 (LO1)
/ESC4/GLB: R61.1, U11.10 (LO2)
/ESC4/GLC: R63.1, U11.9 (LO3)
/ESC4/MotorA: C83.1, Q19.1 (S), Q20.3 (D), R66.1, U11.18 (VS1); also elsewhere on the board
/ESC4/MotorB: C35.1, Q21.1 (S), Q22.3 (D), R69.1, U11.15 (VS2); also elsewhere on the board
/ESC4/MotorC: C39.1, Q23.1 (S), Q24.3 (D), R72.1, U11.12 (VS3); also elsewhere on the board
/ESC4/vdda: C78.1, R77.1, U10.5 (VDDA)
/M2: R5.1; also elsewhere on the board
/M3: R41.1; also elsewhere on the board
/M4: R59.1; also elsewhere on the board
GND: C44.2, C45.2, C46.2, C63.2, C64.2, C65.2, C66.2, C77.2, C78.2, C79.2, C80.2, C88.2, Q8.1 (S), Q10.1 (S), Q12.1 (S), Q14.1 (S), Q16.1 (S), Q18.1 (S), Q20.1 (S), Q22.1 (S), Q24.1 (S), R4.2, R11.1, R14.1, R35.1, R40.2, R47.1, R50.1, R53.1, R58.2, R65.1, R68.1, R71.1, U6.16 (VSS), U6.29 (VSS), U7.6 (COM), U7.25 (COM), U8.16 (VSS), U8.29 (VSS), U9.6 (COM), U9.25 (COM), U10.16 (VSS), U10.29 (VSS), U11.6 (COM), U11.25 (COM); also elsewhere on the board
unnamed: Q7.2 (G), R1.2
unnamed: Q8.2 (G), R2.2
unnamed: Q9.2 (G), R6.2
unnamed: Q10.2 (G), R7.2
unnamed: Q11.2 (G), R8.2
unnamed: Q12.2 (G), R9.2
unnamed: Q13.2 (G), R37.2
unnamed: Q14.2 (G), R38.2
unnamed: Q15.2 (G), R42.2
unnamed: Q16.2 (G), R43.2
unnamed: Q17.2 (G), R44.2
unnamed: Q18.2 (G), R45.2
unnamed: Q19.2 (G), R55.2
unnamed: Q20.2 (G), R56.2
unnamed: Q21.2 (G), R60.2
unnamed: Q22.2 (G), R61.2
unnamed: Q23.2 (G), R62.2
unnamed: Q24.2 (G), R63.2
unnamed: R4.1, U6.1 (BOOT0)
unnamed: C46.1, R3.1, U6.4 (NRST)
unnamed: TP2.1 (1_1), U6.21 (PA13)
unnamed: TP3.1 (1_1), U6.22 (PA14)
unnamed: R5.2, U6.25 (PB4)
unnamed: C59.2, U7.20 (VB1)
unnamed: C33.2, U7.17 (VB2)
unnamed: C37.2, U7.14 (VB3)
unnamed: R40.1, U8.1 (BOOT0)
unnamed: C66.1, R39.1, U8.4 (NRST)
unnamed: TP5.1 (1_1), U8.21 (PA13)
unnamed: TP6.1 (1_1), U8.22 (PA14)
unnamed: R41.2, U8.25 (PB4)
unnamed: C73.2, U9.20 (VB1)
unnamed: C34.2, U9.17 (VB2)
unnamed: C38.2, U9.14 (VB3)
unnamed: R58.1, U10.1 (BOOT0)
unnamed: C80.1, R57.1, U10.4 (NRST)
unnamed: TP7.1 (1_1), U10.21 (PA13)
unnamed: TP8.1 (1_1), U10.22 (PA14)
unnamed: R59.2, U10.25 (PB4)
unnamed: C83.2, U11.20 (VB1)
unnamed: C35.2, U11.17 (VB2)
unnamed: C39.2, U11.14 (VB3)

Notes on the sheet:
Bootstrap capacitors for high side N-MOS switching
Gate Driver
MOSFET, low and high side for each phase
Single sheet instance of an ESC, duplicated 4 times
Microcontroller: AT32
SWC flashing
(gate driver has integrated diode)
06/06/2026
BEMF Feedback network
LPF on VDDA

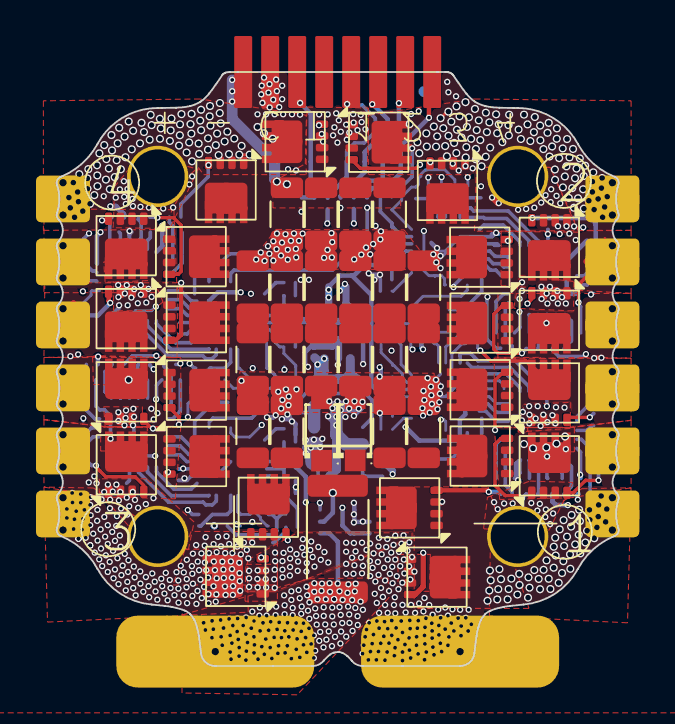
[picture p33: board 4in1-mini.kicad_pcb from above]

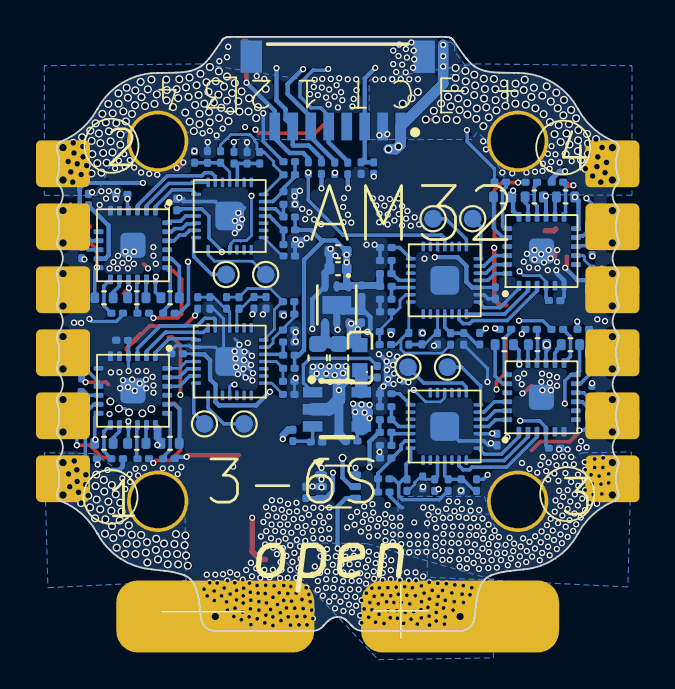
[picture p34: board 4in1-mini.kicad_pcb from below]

Board: 6 copper layers, 31.2 x 33.0 mm, 186 parts (138 on the bottom side), 150 nets.

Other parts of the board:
CL33, CL34, CL35, CL36, CL38, CL39, CL40, CL42, CL43, CL44, CL45, CL46, CL47, CL48, CL49, CL50, CL51, CL54, CL55: 10uF; C_1206_3216Metric

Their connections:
+BATT: CL33.1, CL34.1, CL35.1, CL36.1, CL38.1, CL39.1, CL40.1, CL42.1, CL43.1, CL44.1, CL45.1, CL46.1, CL47.1, CL48.1, CL49.1, CL50.1, CL51.1, CL54.1, CL55.1; also elsewhere on the board
GND: CL33.2, CL34.2, CL35.2, CL36.2, CL38.2, CL39.2, CL40.2, CL42.2, CL43.2, CL44.2, CL45.2, CL46.2, CL47.2, CL48.2, CL49.2, CL50.2, CL51.2, CL54.2, CL55.2; also elsewhere on the board

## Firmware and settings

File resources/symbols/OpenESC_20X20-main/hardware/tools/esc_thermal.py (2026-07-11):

#!/usr/bin/env python3
"""
4in1 ESC Power Loss & Thermal Calculator

Models AM32 trapezoidal 6-step commutation with steady-state and transient thermal.
Supports both 20x20 and 30x30 ESC variants with datasheet-verified parameters.

Datasheets:
  20x20: SP40N03GNJ (Siliup Ver-1.2) + NSG2065Q (NSIC V1.0), Rg=15Ω
  30x30: SP40N01GHNK (Siliup Ver-1.1) + NSG2065Q (NSIC V1.0), Rg=8Ω
"""

import argparse
import math

# ═══════════════════════════════════════════════════════════════
#  MOSFET profiles — all values from datasheets
# ═══════════════════════════════════════════════════════════════

PROFILES = {
    "20x20": {
        "name":         "20×20  SP40N03GNJ (3×3mm)",
        # ── SP40N03GNJ datasheet (Ver-1.2) ──
        "rds_on":       2.9e-3,     # Ω typ @ Vgs=10V, ID=20A, 25°C
        "rds_on_max":   3.7e-3,     # Ω max
        "rds_tempco":   1.45,       # normalized @ 100°C (p3 curve)
        "rds_tempco_150": 1.70,     # normalized @ 150°C
        "qg_at_10v":    15e-9,      # C  (from gate charge curve p3 @ Vgs=10V)
        "qgd":          5.5e-9,     # C  gate-drain (Miller) charge
        "vgs":          10.0,       # V
        "rg":           15.0,       # Ω  external gate resistor
        "v_plateau":    3.0,        # V  Miller plateau (transfer curve p3)
        # Switching: Qgd / I_gate through Rg
        #   I_on  = (10-3)/15 = 0.47A → tr = 5.5nC/0.47A = 11.7ns
        #   I_off = 3/15      = 0.20A → tf = 5.5nC/0.20A = 27.5ns
        "tr":           11.7e-9,
        "tf":           27.5e-9,
        "vf_body_cold": 0.80,       # V  @ ~30A, 25°C (p4 curve extrapolated)
        "vf_body_hot":  0.65,       # V  @ ~30A, 100°C
        "trr":          14e-9,      # s  (p2)
        "qrr":          23e-9,      # C  (p2)
        "rth_jc":       2.27,       # °C/W (p2)
        "pd_max":       55.0,       # W
        "tj_max":       150.0,      # °C
        # Board
        "board_mm":     20,         # mm mounting pattern
        "board_area":   1030.0,     # mm² actual PCB (~31×33mm, from Edge.Cuts)
        "r_copper":     3.2e-3,     # Ω per phase trace
        "r_shunt":      0.2e-3,     # Ω
        "layers":       6,
        "oz_outer":     1,          # oz copper
        "oz_inner":     0.5,
    },
    "30x30": {
        "name":         "30×30  SP40N01GHNK (5×6mm)",
        # ── SP40N01GHNK datasheet (Ver-1.1) ──
        "rds_on":       1.2e-3,     # Ω typ @ Vgs=10V, ID=20A, 25°C
        "rds_on_max":   1.5e-3,     # Ω max
        "rds_tempco":   1.45,       # normalized @ 100°C (p3 curve)
        "rds_tempco_150": 1.70,     # normalized @ 150°C
        "qg_at_10v":    65e-9,      # C  (from gate charge curve p3 @ Vgs=10V)
        "qgd":          15.5e-9,    # C  gate-drain (Miller) charge
        "vgs":          10.0,       # V
        "rg":           8.0,        # Ω  external gate resistor
        "v_plateau":    3.5,        # V  Miller plateau (transfer curve p3, higher Vth)
        # Switching: Qgd / I_gate through Rg
        #   I_on  = (10-3.5)/8 = 0.81A → tr = 15.5nC/0.81A = 19.1ns
        #   I_off = 3.5/8      = 0.44A → tf = 15.5nC/0.44A = 35.2ns
        "tr":           19.1e-9,
        "tf":           35.2e-9,
        "vf_body_cold": 0.75,       # V  @ ~30A, 25°C (p3 source-drain diode curve)
        "vf_body_hot":  0.60,       # V  @ ~30A, 100°C
        "trr":          29e-9,      # s  (p2)
        "qrr":          113e-9,     # C  (p2) — much higher than SP40N03GNJ
        "rth_jc":       0.96,       # °C/W (p2) — better, larger package
        "pd_max":       130.0,      # W
        "tj_max":       150.0,      # °C
        # Board
        "board_mm":     30,         # mm mounting pattern
        "board_area":   1770.0,     # mm² actual PCB (~42×43mm, from Edge.Cuts)
        "r_copper":     2.0e-3,     # Ω per phase (wider traces, more area)
        "r_shunt":      0.2e-3,     # Ω
        "layers":       6,
        "oz_outer":     1,
        "oz_inner":     0.5,
    },
}

# ─── NSG2065Q gate driver (shared) ───
GATE_DRIVER = {
    "dead_time_typ":  200e-9,   # s  hardware dead time (100-300ns, p6)
    "dead_time_min":  100e-9,
    "dead_time_max":  300e-9,
    "io_source":      1.2,      # A
    "io_sink":        1.5,      # A
}

# ─── Thermal scenarios ───
# h = convective heat transfer coefficient (W/m²·K)
# θ_board = 1 / (h × A_both_sides)
THERMAL_SCENARIOS = {
    "still":        {"h": 15,   "label": "Still air (bench)"},
    "light_flow":   {"h": 50,   "label": "Light prop wash (~3m/s)"},
    "strong_flow":  {"h": 100,  "label": "Strong prop wash (~8m/s)"},
    "direct_blast": {"h": 150,  "label": "Direct motor blast (>10m/s)"},
}

# ─── PCB stackup options for thermal comparison ───
# Copper thickness: 1oz=35µm, 2oz=70µm, 0.5oz=17.5µm
# Thermal conductivity: Cu=385 W/(m·K), FR4=0.3 W/(m·K)
PCB_OPTIONS = {
    "jlcpcb_6L_1oz": {
        "label":    "JLCPCB 6L 1oz/0.5oz (current)",
        "oz_outer": 1.0, "oz_inner": 0.5, "layers": 6,
        "notes":    "Standard, free POFV via-in-pad",
    },
    "jlcpcb_6L_2oz": {
        "label":    "JLCPCB 6L 2oz/2oz (max multilayer)",
        "oz_outer": 2.0, "oz_inner": 2.0, "layers": 6,
        "notes":    "Max Cu at JLCPCB for 6L, ~2x bare board cost",
    },
    "jlcpcb_4L_2oz": {
        "label":    "JLCPCB 4L 2oz/2oz",
        "oz_outer": 2.0, "oz_inner": 2.0, "layers": 4,
        "notes":    "Cheaper than 6L, no free POFV",
    },
    "jlcpcb_6L_3oz": {
        "label":    "JLCPCB 6L 3oz/1oz (industry std ESC)",
        "oz_outer": 3.0, "oz_inner": 1.0, "layers": 6,
        "notes":    "What commercial 35A ESCs use",
    },
    "pcbway_6L_4oz": {
        "label":    "PCBWay 6L 4oz/2oz (heavy Cu)",
        "oz_outer": 4.0, "oz_inner": 2.0, "layers": 6,
        "notes":    "PCBWay supports >2oz on multilayer, premium cost",
    },
}


def board_theta(area_mm2: float, h: float) -> float:
    """Board-to-ambient thermal resistance (°C/W), both sides convecting."""
    area_m2 = area_mm2 * 2.0 * 1e-6
    return 1.0 / (h * area_m2)


def board_thermal_mass(area_mm2: float, layers: int, oz_outer: float, oz_inner: float,
                       board_thickness_mm: float = 1.6) -> float:
    """Board thermal capacitance in J/K.

    Accounts for FR-4 substrate and copper layers.
    FR-4: ρ=1.85 g/cm³, cp=1.1 J/(g·K)
    Cu:   ρ=8.96 g/cm³, cp=0.385 J/(g·K)
    """
    area_cm2 = area_mm2 * 1e-2  # mm² → cm²

    # FR-4 volume (approximate: total thickness minus copper)
    cu_outer_mm = oz_outer * 0.035  # mm per oz
    cu_inner_mm = oz_inner * 0.035 if oz_inner else 0.0175
    n_inner = max(layers - 2, 0)
    total_cu_mm = 2 * cu_outer_mm + n_inner * cu_inner_mm
    fr4_mm = board_thickness_mm - total_cu_mm
    fr4_vol_cm3 = area_cm2 * fr4_mm * 0.1  # cm²×mm→cm³ needs ×0.1
    fr4_mass = fr4_vol_cm3 * 1.85
    fr4_cth = fr4_mass * 1.1

    # Copper volume
    cu_vol_cm3 = area_cm2 * total_cu_mm * 0.1
    cu_mass = cu_vol_cm3 * 8.96
    cu_cth = cu_mass * 0.385

    return fr4_cth + cu_cth


def copper_resistance_scaled(r_base: float, oz_base: float, oz_new: float) -> float:
    """Scale copper trace resistance for different copper weight.
    R ∝ 1/thickness, so doubling oz halves resistance.
    """
    return r_base * oz_base / oz_new


def calc_phase_losses(i: float, v_bus: float, duty: float, f_pwm: float,
                      comp_pwm: bool, dead_time: float, p: dict,
                      r_copper_override: float = None) -> dict:
    """Calculate losses for one active phase pair."""
    rds = p["rds_on"] * p["rds_tempco"]  # hot Rds(on)
    vf = p["vf_body_hot"]
    r_cu = r_copper_override if r_copper_override else p["r_copper"]

    # Conduction
    p_cond_hs = i**2 * rds * duty
    if comp_pwm:
        p_cond_ls = i**2 * rds * (1.0 - duty)
        p_body = 0.0
    else:
        p_cond_ls = 0.0
        p_body = vf * i * (1.0 - duty)
    p_cond_low = i**2 * rds  # LOW-phase FET, 100% on

    # Switching (Miller plateau crossing)
    p_switch = 0.5 * v_bus * i * (p["tr"] + p["tf"]) * f_pwm

    # Dead time (both edges per PWM cycle)
    p_dead = vf * i * dead_time * 2.0 * f_pwm

    # Reverse recovery (Qrr-based model)
    p_rr = p["qrr"] * v_bus * f_pwm

    # Gate drive (HS at f_pwm, LS at commutation freq ~200Hz)
    p_gate = p["qg_at_10v"] * p["vgs"] * f_pwm + p["qg_at_10v"] * p["vgs"] * 200

    # Copper (both phase traces in the current path)
    p_copper = i**2 * r_cu * 2.0

    # Shunt
    p_shunt = i**2 * p["r_shunt"]

    p_fet = p_cond_hs + p_cond_ls + p_body + p_cond_low + p_switch + p_dead + p_rr + p_gate
    p_passive = p_copper + p_shunt
    p_total = p_fet + p_passive

    return {
        "p_cond_hs": p_cond_hs, "p_cond_ls": p_cond_ls, "p_body": p_body,
        "p_cond_low": p_cond_low, "p_switch": p_switch, "p_dead": p_dead,
        "p_rr": p_rr, "p_gate": p_gate, "p_copper": p_copper, "p_shunt": p_shunt,
        "p_fet": p_fet, "p_passive": p_passive, "p_total": p_total,
    }


def transient_time_to_tj(p_board: float, theta_ba: float, c_th: float,
                         tj_max: float, t_ambient: float) -> float:
    """Time (seconds) from ambient to Tj_max under constant power.

    Simple first-order RC model: ΔT(t) = ΔT_ss × (1 - e^(-t/τ))
    τ = C_th × θ_ba
    Returns float('inf') if steady-state ΔT < (Tj_max - T_ambient).
    """
    dt_max = tj_max - t_ambient
    dt_ss = p_board * theta_ba
    if dt_ss <= dt_max:
        return float('inf')  # never reaches Tj_max
    tau = c_th * theta_ba
    return -tau * math.log(1.0 - dt_max / dt_ss)


def print_full_report(profile_key: str, i: float, v_bus: float, duty: float,
                      f_pwm: float, comp_pwm: bool, dead_time: float, n_active: int):
    p = PROFILES[profile_key]
    rds_hot = p["rds_on"] * p["rds_tempco"]
    losses = calc_phase_losses(i, v_bus, duty, f_pwm, comp_pwm, dead_time, p)

    p_board = losses["p_total"] * n_active
    p_motor = v_bus * i * duty * n_active
    eff = p_motor / (p_motor + p_board) * 100 if p_motor > 0 else 0

    print("=" * 70)
    print(f"  4in1 ESC Power Loss Report  —  {p['name']}")
    print(f"  AM32 6-Step Trapezoidal  |  NSG2065Q gate driver")
    print("=" * 70)
    print(f"  Battery voltage:      {v_bus:.1f} V")
    print(f"  Phase current:        {i:.1f} A")
    print(f"  Duty cycle:           {duty*100:.1f}%")
    print(f"  PWM frequency:        {f_pwm/1e3:.0f} kHz")
    print(f"  Dead time:            {dead_time*1e9:.0f} ns  (NSG2065Q HW)")
    print(f"  Comp PWM:             {'ON' if comp_pwm else 'OFF'}")
    print(f"  Gate resistor:        {p['rg']:.0f}Ω  →  tr={p['tr']*1e9:.1f}ns  tf={p['tf']*1e9:.1f}ns")
    print(f"  Rds(on):              {p['rds_on']*1e3:.1f}mΩ cold → {rds_hot*1e3:.1f}mΩ hot (×{p['rds_tempco']})")
    print(f"  Active phases:        {n_active}")
    print("-" * 70)

    print(f"\n  Per phase pair (HS + LS MOSFET + copper):")
    print(f"    HS conduction:     {losses['p_cond_hs']:7.3f} W  (I²×Rds×D)")
    if comp_pwm:
        print(f"    LS sync rect:      {losses['p_cond_ls']:7.3f} W  (I²×Rds×(1-D))")
    else:
        print(f"    Body diode:        {losses['p_body']:7.3f} W  (Vf×I×(1-D))")
    print(f"    LOW-phase FET:     {losses['p_cond_low']:7.3f} W  (I²×Rds, 100%)")
    print(f"    Switching:         {losses['p_switch']:7.3f} W")
    print(f"    Dead time:         {losses['p_dead']:7.3f} W")
    print(f"    Reverse recovery:  {losses['p_rr']:7.3f} W  (Qrr={p['qrr']*1e9:.0f}nC)")
    print(f"    Gate drive:        {losses['p_gate']:7.3f} W")
    print(f"    ────────────────────────────────────────")
    print(f"    FET subtotal:      {losses['p_fet']:7.3f} W")
    print(f"    Copper (×2):       {losses['p_copper']:7.3f} W  ({p['r_copper']*1e3:.1f}mΩ/phase)")
    print(f"    Shunt:             {losses['p_shunt']:7.3f} W")
    print(f"    ────────────────────────────────────────")
    print(f"    Phase total:       {losses['p_total']:7.3f} W")

    print(f"\n  Board totals ({n_active} phases):")
    print(f"    Heat dissipation:  {p_board:7.2f} W")
    print(f"    Motor output:      {p_motor:7.1f} W")
    print(f"    Efficiency:        {eff:7.1f}%")

    # ─── Steady-state thermal ───
    area = p["board_area"]
    c_th = board_thermal_mass(area, p["layers"], p["oz_outer"], p["oz_inner"])

    print(f"\n  Steady-state thermal ({area:.0f}mm² board, {p['layers']}L "
          f"{p['oz_outer']:.0f}oz/{p['oz_inner']}oz):")
    print(f"  {'Scenario':<28s} {'θ':>6s}  {'ΔT':>6s}  {'Tj@25°C':>7s}  {'Tj@40°C':>7s}")
    print(f"  {'-'*62}")

    for key, sc in THERMAL_SCENARIOS.items():
        theta = board_theta(area, sc["h"])
        dt = p_board * theta
        tj25 = 25 + dt
        tj40 = 40 + dt
        w = " !! EXCEED" if tj25 > 150 else " ! HOT" if tj25 > 125 else ""
        print(f"  {sc['label']:<28s} {theta:5.1f}°/W  +{dt:4.0f}°C  {tj25:6.0f}°C  {tj40:6.0f}°C{w}")

    # ─── Transient thermal ───
    print(f"\n  Transient thermal (time to Tj=150°C from 25°C ambient):")
    print(f"  Board thermal mass: {c_th:.2f} J/K")
    print(f"  {'Scenario':<28s} {'τ':>6s}  {'t to 150°C':>10s}")
    print(f"  {'-'*50}")

    for key, sc in THERMAL_SCENARIOS.items():
        theta = board_theta(area, sc["h"])
        tau = c_th * theta
        t_max = transient_time_to_tj(p_board, theta, c_th, 150, 25)
        if t_max == float('inf'):
            t_str = "never"
        elif t_max < 1:
            t_str = f"{t_max*1000:.0f} ms"
        else:
            t_str = f"{t_max:.1f} s"
        print(f"  {sc['label']:<28s} {tau:5.1f}s   {t_str:>10s}")

    # ─── MOSFET limits ───
    p_worst_fet = max(
        losses["p_cond_hs"] + losses["p_switch"] + losses["p_dead"]/2 + losses["p_rr"],
        losses["p_cond_low"] + losses["p_body"] + losses["p_dead"]/2,
    )
    print(f"\n  MOSFET: RθJC={p['rth_jc']:.2f}°C/W  Pd_max={p['pd_max']:.0f}W  Tj_max={p['tj_max']:.0f}°C")
    print(f"  Worst single FET: {p_worst_fet:.2f}W → ΔTjc={p_worst_fet*p['rth_jc']:.1f}°C above pad")
    print("=" * 70)


def sweep(profile_key: str, currents: list, v_bus: float, duty: float,
          f_pwm: float, comp_pwm: bool, dead_time: float, n_active: int):
    p = PROFILES[profile_key]
    area = p["board_area"]
    c_th = board_thermal_mass(area, p["layers"], p["oz_outer"], p["oz_inner"])
    theta_fly = board_theta(area, 100)  # strong prop wash

    print()
    print(f"  {p['name']}  @  {v_bus:.0f}V  {duty*100:.0f}%  {f_pwm/1e3:.0f}kHz  "
          f"comp_pwm={'ON' if comp_pwm else 'OFF'}")
    print(f"  Board: {area:.0f}mm²  θ_propwash={theta_fly:.1f}°/W  C_th={c_th:.2f}J/K")
    print(f"  {'I':>6s}  {'Phase':>7s}  {'Board':>7s}  {'Eff':>5s}  "
          f"{'Tj_fly':>6s}  {'t→150°C':>8s}  {'Rating':>12s}")
    print(f"  {'-'*66}")

    for current in currents:
        losses = calc_phase_losses(current, v_bus, duty, f_pwm, comp_pwm, dead_time, p)
        p_board = losses["p_total"] * n_active
        p_motor = v_bus * current * duty * n_active
        eff = p_motor / (p_motor + p_board) * 100 if p_motor > 0 else 0
        tj_fly = 25 + p_board * theta_fly
        t_max = transient_time_to_tj(p_board, theta_fly, c_th, 150, 25)

        if t_max == float('inf'):
            t_str = "∞"
            if tj_fly < 100:
                rating = "continuous"
            elif tj_fly < 125:
                rating = "continuous*"
            else:
                rating = "marginal"
        elif t_max > 10:
            t_str = f"{t_max:.0f}s"
            rating = "burst OK"
        elif t_max > 3:
            t_str = f"{t_max:.1f}s"
            rating = "burst limit"
        else:
            t_str = f"{t_max:.1f}s"
            rating = "DANGER"

        print(f"  {current:5.0f}A  {losses['p_total']:6.2f}W  {p_board:6.1f}W  "
              f"{eff:4.1f}%  {tj_fly:5.0f}°C  {t_str:>8s}  {rating:>12s}")

    print()
    print("  continuous  = Tj < 100°C steady-state in prop wash")
    print("  continuous* = Tj 100-125°C (hot but survivable)")
    print("  marginal    = Tj 125-150°C (near limit)")
    print("  burst OK    = >10s to Tj_max (typical punch-out)")
    print("  burst limit = 3-10s to Tj_max")
    print()


def compare_boards(v_bus: float, duty: float, f_pwm: float, comp_pwm: bool,
                   dead_time: float, n_active: int):
    """Side-by-side comparison of both ESC variants."""
    currents = [5, 10, 15, 20, 25, 30, 35, 40, 50]

    print()
    print("=" * 78)
    print("  BOARD COMPARISON  —  20×20 vs 30×30")
    print(f"  {v_bus:.0f}V  {duty*100:.0f}% duty  {f_pwm/1e3:.0f}kHz  "
          f"comp_pwm={'ON' if comp_pwm else 'OFF'}  {n_active} phases")
    print("=" * 78)

    for key in ["20x20", "30x30"]:
        p = PROFILES[key]
        area = p["board_area"]
        c_th = board_thermal_mass(area, p["layers"], p["oz_outer"], p["oz_inner"])
        theta_fly = board_theta(area, 100)
        rds_hot = p["rds_on"] * p["rds_tempco"]

        print(f"\n  {p['name']}")
        print(f"  Rds(on)={rds_hot*1e3:.1f}mΩ hot  Rg={p['rg']:.0f}Ω  "
              f"Qrr={p['qrr']*1e9:.0f}nC  RθJC={p['rth_jc']:.2f}°/W")
        print(f"  θ_fly={theta_fly:.1f}°/W  C_th={c_th:.2f}J/K  "
              f"R_cu={p['r_copper']*1e3:.1f}mΩ/phase")
        print(f"  {'I':>6s}  {'Board W':>7s}  {'Eff':>5s}  "
              f"{'Tj_fly':>6s}  {'t→150°C':>8s}")
        print(f"  {'-'*44}")

        for current in currents:
            losses = calc_phase_losses(current, v_bus, duty, f_pwm, comp_pwm, dead_time, p)
            p_board = losses["p_total"] * n_active
            p_motor = v_bus * current * duty * n_active
            eff = p_motor / (p_motor + p_board) * 100 if p_motor > 0 else 0
            tj_fly = 25 + p_board * theta_fly
            t_max = transient_time_to_tj(p_board, theta_fly, c_th, 150, 25)
            t_str = "∞" if t_max == float('inf') else f"{t_max:.1f}s" if t_max < 60 else f"{t_max/60:.0f}m"
            warn = " !!" if tj_fly > 150 else " !" if tj_fly > 125 else ""
            print(f"  {current:5.0f}A  {p_board:6.1f}W  {eff:4.1f}%  "
                  f"{tj_fly:5.0f}°C  {t_str:>8s}{warn}")

    print()


def compare_pcb_options(profile_key: str, i: float, v_bus: float, duty: float,
                        f_pwm: float, comp_pwm: bool, dead_time: float, n_active: int):
    """Show impact of different PCB stackups on thermal performance."""
    p = PROFILES[profile_key]

    print()
    print(f"  PCB stackup comparison for {p['name']} @ {i:.0f}A {v_bus:.0f}V {duty*100:.0f}%")
    print("=" * 78)
    print(f"  {'Option':<38s} {'R_cu':>5s} {'Board W':>7s} {'Tj_fly':>6s} "
          f"{'t→150':>6s} {'Notes'}")
    print(f"  {'-'*76}")

    for opt_key, opt in PCB_OPTIONS.items():
        r_cu = copper_resistance_scaled(p["r_copper"], p["oz_outer"], opt["oz_outer"])
        losses = calc_phase_losses(i, v_bus, duty, f_pwm, comp_pwm, dead_time, p,
                                   r_copper_override=r_cu)
        p_board = losses["p_total"] * n_active
        area = p["board_area"]
        c_th = board_thermal_mass(area, opt["layers"], opt["oz_outer"], opt["oz_inner"])
        theta_fly = board_theta(area, 100)
        tj = 25 + p_board * theta_fly
        t_max = transient_time_to_tj(p_board, theta_fly, c_th, 150, 25)
        t_str = "∞" if t_max == float('inf') else f"{t_max:.1f}s"

        print(f"  {opt['label']:<38s} {r_cu*1e3:4.1f}  {p_board:6.1f}W  "
              f"{tj:5.0f}°C  {t_str:>5s}  {opt['notes']}")

    print()


def main():
    parser = argparse.ArgumentParser(
        description="4in1 ESC power loss calculator (AM32 6-step trapezoidal)",
        formatter_class=argparse.RawDescriptionHelpFormatter,
        epilog="""\
examples:
  %(prog)s -p 20x20 -i 30 -v 16.8 -d 80
  %(prog)s -p 30x30 -i 40 -v 25.2 -d 50 --comp-pwm
  %(prog)s -p 20x20 --sweep 5,10,15,20,25,30,35,40
  %(prog)s --compare -v 16.8 -d 80
  %(prog)s --pcb-options -p 30x30 -i 30 -v 16.8 -d 80
""")
    parser.add_argument("-p", "--profile", choices=["20x20", "30x30"], default="20x20",
                        help="ESC variant (default: 20x20)")
    parser.add_argument("-i", "--current", type=float, default=30.0)
    parser.add_argument("-v", "--voltage", type=float, default=16.8)
    parser.add_argument("-d", "--duty", type=float, default=80.0)
    parser.add_argument("-f", "--pwm-freq", type=float, default=24000)
    parser.add_argument("--dead-time", type=float, default=200e-9)
    parser.add_argument("--comp-pwm", action="store_true")
    parser.add_argument("-n", "--num-active", type=int, default=4)
    parser.add_argument("--sweep", type=str, default=None)
    parser.add_argument("--compare", action="store_true",
                        help="compare 20x20 vs 30x30 side by side")
    parser.add_argument("--pcb-options", action="store_true",
                        help="compare PCB stackup options")

    args = parser.parse_args()
    duty = args.duty / 100.0

    if args.compare:
        compare_boards(args.voltage, duty, args.pwm_freq, args.comp_pwm,
                       args.dead_time, args.num_active)
    elif args.pcb_options:
        compare_pcb_options(args.profile, args.current, args.voltage, duty,
                            args.pwm_freq, args.comp_pwm, args.dead_time, args.num_active)
    elif args.sweep:
        currents = [float(x) for x in args.sweep.split(",")]
        sweep(args.profile, currents, args.voltage, duty, args.pwm_freq,
              args.comp_pwm, args.dead_time, args.num_active)
    else:
        print_full_report(args.profile, args.current, args.voltage, duty,
                          args.pwm_freq, args.comp_pwm, args.dead_time, args.num_active)


if __name__ == "__main__":
    main()

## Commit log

2026-07-06 Document comparison of STM32 microcontrollers
    Added detailed comparison between STM32F405RGT6 and STM32F407Ix, explaining reasons for choosing the former for flight controllers.
2026-07-06 Update journal with insights on F405RGT6 and soldering
    Added personal notes on component selection and soldering temperature.
2026-07-06 Update journal with key focus areas for wiring
2026-07-06 Update journal with STM32F405RGTx details
    Added notes on STM32F405RGTx and pin assignments.
2026-07-06 Document KICAD crash experience and add image
    Added an image reference and additional comments about KICAD crashing.
2026-07-06 hell yeah
    [Dragonfly.kicad_sch]
2026-07-06 here we goo
    [TSX-3225.step]
2026-07-07 Fix capacitor values and include missing images
    Corrected capacitor values and added missing images.
2026-07-07 Insert missing images in journal.md
    Added missing images to the journal.
2026-07-07 Update journal with power supply clarifications
    Clarified the roles of power supplies VDD33, VBAT, and VDD33A in the journal.
2026-07-08 Fix ICM-20602 KICAD symbol and pin connections
    Corrected the KICAD symbols for the ICM-20602 to match the reference schematics. Ensured all pins are connected properly.
2026-07-08 Create AT32F421G8U7 refrance schematics.pdf
2026-07-10 Update journal with component clarification and images
    Clarified that MAX7456EUI+ and AT7456E are identical components with the same KICAD symbol and footprint. Added images and completed SOD section.
2026-07-10 Update journal with hardware changes and notes
    Removed USB C due to pin conflicts with ESC. Added notes on BMP280 pin connections and AI assistance.
2026-07-10 Update journal with schematics and ERC notes
    Added notes on schematics completion and upcoming ERC errors.
2026-07-10 Update journal with notes on schematic issues
    Added a note about difficulties finding reference schematics.
2026-07-11 Document PCB design considerations and dimensions
    Added a note about the PCB design decision and dimensions.
2026-07-12 Replace JST with test pads for space efficiency
    Added test points footprints to replace JST connectors to save space.
2026-07-12 Update journal with image and KICAD note
    Added an image to the journal entry and noted uncertainty about KICAD changes.
2026-07-13 Update journal with routing challenges and KICad crash
    Document issues faced during routing and software crash.
2026-07-14 Revise journal entry for PCB and CAD progress
    Updated journal entry with progress on PCB and CAD work.
2026-07-14 Create EMAX AVAN FLOW CW.STEP
    [EMAX AVAN FLOW CW.STEP]
2026-07-14 Create dragonfly CAD.20260714-233235.FCBak
2026-07-14 Update dragonfly CAD.FCStd
2026-07-14 Create EMAX AVAN FLOW.JPG
2026-07-15 Create Assemblage - Runcam Camera FPV.IGS
2026-07-15 Create Assemblage - Runcam Camera FPV.rpt
2026-07-15 Create Assemblage - Runcam Camera FPV.SLDPRT
    [Assemblage - Runcam Camera FPV.SLDPRT]
2026-07-15 Create dragonfly CAD.20260715-005538.FCBak
2026-07-15 Create TATTU 1800mah 4s 01.JPG
2026-07-15 Create dragonfly CAD.20260715-111102.FCBak
2026-07-15 Create Cam wall.step
    [Cam wall.step]
2026-07-15 Create dragonfly CAD full.step
    [dragonfly CAD full.step]
2026-07-15 Create FOXEER TOOTHLESS 2 NANO CAMERA.stl
    [FOXEER TOOTHLESS 2 NANO CAMERA.stl]
2026-07-15 Create FOXEER TOOTHLESS 2 NANO CAMERA.stp
    [FOXEER TOOTHLESS 2 NANO CAMERA.stp]
2026-07-15 Revise journal entry on CAD and firmware setup
    Updated journal entry with progress on CAD and firmware.
2026-07-15 bom added
    [Dragonfly BOM.csv, Dragonfly.csv]

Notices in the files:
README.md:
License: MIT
